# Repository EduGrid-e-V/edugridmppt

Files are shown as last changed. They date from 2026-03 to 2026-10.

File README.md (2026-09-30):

<p align="center">
  EduGrid logo
</p>

<h1 align="center">EduGrid MPPT</h1>

<p align="center">
  <strong>Learn solar energy by trying it.</strong><br>
  A friendly, open-source learning kit for renewable energy education.
</p>

<p align="center">
  Sun icon
  &nbsp;&nbsp;
  Learning icon
</p>

EduGrid MPPT is part of the EduGrid e.V initiative for free education in renewable energies. It is made for students, teachers, workshops, and curious people who want to understand solar power with their own hands.

You do not need to be an expert to begin. Start by moving the slider, watching the display, and seeing how much power a small solar panel can produce. Later, when you feel ready, you can open the code and teach the board your own strategy for finding more power.

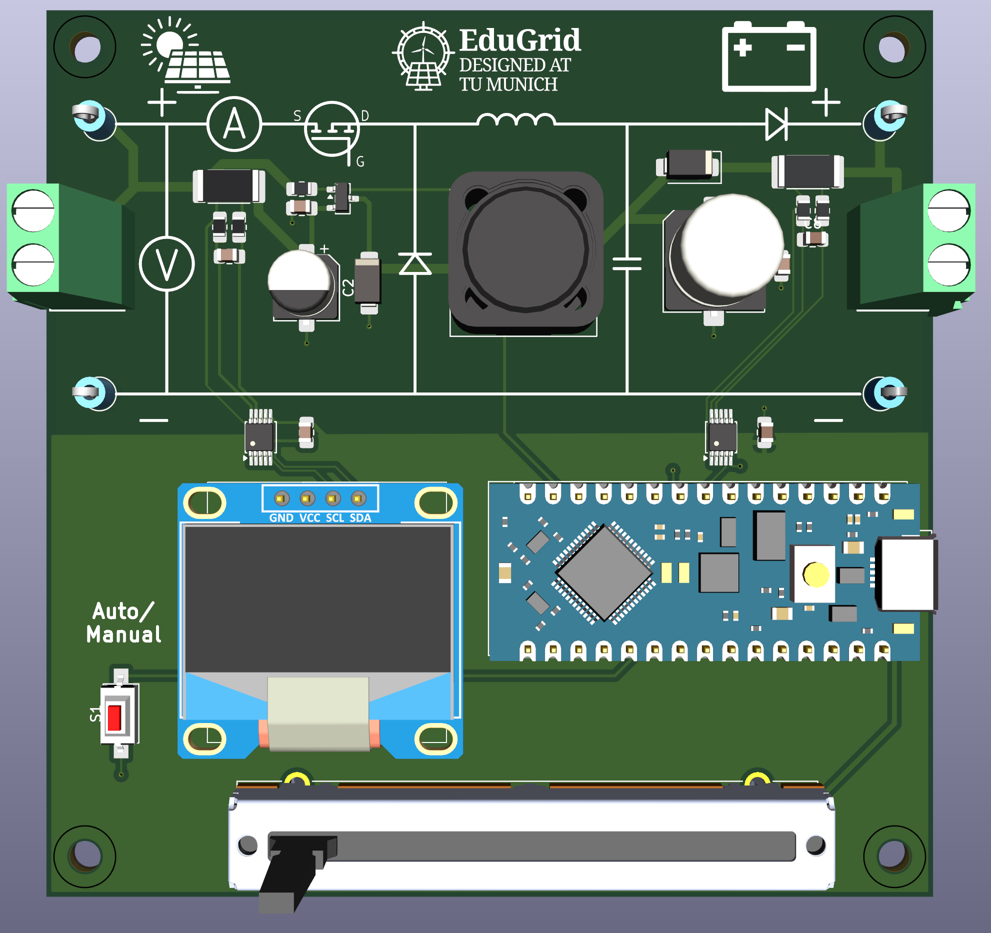
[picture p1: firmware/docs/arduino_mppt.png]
EduGrid MPPT board


## What You Can Discover

- How sunlight becomes electrical power.
- Why a solar panel has a "best point" where it gives the most energy.
- How a small controller can search for that point automatically.
- How coding, electronics, and renewable energy connect in one real project.

This is not just a board and some code. It is a small learning environment: measure something real, ask why it happens, change one thing, and try again.

## Choose Your Path

| I want to... | Start here |
| --- | --- |
| learn the project step by step | [Student Workbook](docs/STUDENT_WORKBOOK.md) |
| upload the firmware to the board | [Firmware Instructions](firmware/README.md) |
| look at the circuit and PCB | [Hardware Files](hardware/README.md) |
| explore the web dashboard | [Dashboard Source](frontend/README.md) |

## ESP32 web pages

Precompiled downloads are available from [GitHub Releases](https://github.com/EduGrid-e-V/edugridmppt/releases). Each tagged release provides an Arduino Nano `.hex`, an ESP32 `firmware.bin`, a dashboard `littlefs.bin`, and a complete ZIP with checksums, bootloader and partition images, instructions, and the standalone simulation page. GitHub Actions builds the same package on every `main` push; version tags publish it as a Release. GitLab CI also packages tagged commits as pipeline artifacts.

For an ESP32 already running the OTA-capable firmware, upload `firmware.bin` and `littlefs.bin` separately at `/admin`. The bootloader and partition images require USB flashing; do not upload them through the browser. Keep a USB recovery path available, especially for the first test release.

When connected to the board's open `EduGrid_XX` WiFi network, open
`http://192.168.4.1/` for the dashboard. In the real experiment view,
select **Downloads** in the header to find recorded CSV files. The
`/downloads` page can also be opened directly.

`http://192.168.4.1/admin` is the firmware and filesystem update page.
Neither page requires a password. Anyone connected to the open EduGrid WiFi
can update the board or delete recordings; use it in a supervised setting.
See the [firmware instructions](firmware/README.md) for the update workflow.

## For Students

Begin with the workbook and the manual experiments. Your first goal is simple: find the duty setting where the solar panel produces the most power.

When you are ready to code, your workspace is:

```text
firmware/src/mppt_alg.cpp
```

Small changes are welcome. Good experiments often begin with "What happens if I try this?"

## For Teachers

EduGrid MPPT is designed for gentle entry and deeper follow-up. A first lesson can stay fully practical: connect the board, change the operating point, and discuss power. Later lessons can introduce algorithms, sensor data, dashboards, and the structure of embedded software.

The [Student Workbook](docs/STUDENT_WORKBOOK.md) is written so it can be used in class or exported as a PDF for home study.

## The Bigger Picture

EduGrid e.V works to make renewable energy education freely available. This project supports that mission with open learning material, open hardware files, and firmware that students can actually read and change.

Renewable energy becomes less mysterious when learners can touch it, measure it, and improve it. That is the spirit of EduGrid MPPT.

## License

Hardware, firmware, and documentation are each released under different open licenses. See [LICENSE.md](LICENSE.md) for details.

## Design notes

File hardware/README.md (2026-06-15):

# EduGrid MPPT Hardware

This folder contains the KiCad hardware design files for the EduGrid MPPT trainer.

## Main Files

| File or folder | Purpose |
| --- | --- |
| `mppt.kicad_pro` | KiCad project file |
| `mppt.kicad_sch` | Schematic |
| `mppt.kicad_pcb` | PCB layout |
| `library/Library.pretty/` | Project footprints |
| `library/3dmodels/` | 3D models used by the board |
| `mppt-backups/` | KiCad backup files |

## Related Documentation

- [Student Workbook](../docs/STUDENT_WORKBOOK.md) explains the system concept and classroom experiments.
- [Firmware README](../firmware/README.md) explains the firmware, board controls, and supported build environments.

## Notes For Students

The hardware is the physical part of the MPPT system: solar panel input, buck converter power stage, INA226 sensors, OLED display, button, potentiometer, and the Arduino Nano or Arduino Nano ESP32.

When reading the schematic, try to connect each block to the firmware modules:

- Sensors in hardware are read by `firmware/src/sensor_manager.cpp`.
- The gate driver/PWM path is controlled by `firmware/src/pwm_manager.cpp`.
- Button and potentiometer are handled by `firmware/src/input_manager.cpp`.
- Display wiring is used by `firmware/src/display_manager.cpp`.

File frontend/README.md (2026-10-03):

# EduGrid MPPT Dashboard

This is the browser dashboard for the EduGrid MPPT trainer. The same Vue source has two compile-time targets:

- The firmware target is served by the ESP32 from LittleFS and talks to the firmware through WebSockets and HTTP endpoints.
- The standalone target starts in simulation mode and includes the Berry Algorithm Lab in one offline HTML file.

The built dashboard is intentionally self-contained. It should not rely on external CDNs because the ESP32 usually serves it from its own access point. The header language selector switches the dashboard, charts, Berry guidance, and logging UI between English, German, and Spanish immediately. The initial language follows the browser locale; student-edited Berry code is never translated or overwritten. The same built-in translations ship in both firmware and standalone builds, with no runtime network request.

The small header badge shows the build version from `frontend/package.json`. The current `-dev` suffix marks an unreleased build; only a separate Git release tag publishes a release.

## Project Layout

```text
frontend/
  index.html
  package.json
  vite.config.js
  src/
    App.vue
    components/
    services/
```

Key services:

- `src/simulation/SimpleSimulation.js` is the single model used by both frontend simulation paths. It represents the classroom panel as nominally 13.5 V open circuit (capped at 14 V), 180 mA short circuit, and approximately 2 W maximum power, with a fixed 25 ohm load. Manual duty and Berry output span 0–100%; simulated
  0% is the panel open-circuit state.
- `src/services/SimulationWorkerConnector.js` connects all simulation modes—including development and the ESP-hosted page—to the same worker.
- `src/workers/simulation.worker.js` owns the model, real Berry 1.1.0 interpreter, and benchmark in both builds. The firmware build uses an external worker file; the standalone build inlines it for `file://` use.
- The optional physics-model prototype is preserved on the `pv-sim` branch; neither dashboard build depends on it.
- `src/services/EspConnector.js` connects to the ESP32 using `/ws`, `/api/set`, `/api/sweep`, and `/api/sweepdata`.
- `src/components/SimulationScene.vue` only visualizes the sky and emits environmental inputs; it is not a physical model.

## Requirements

- Node.js 20 or newer is recommended for the current Vite version.
- npm
- PlatformIO, when uploading the firmware or LittleFS image to the ESP32.

Install frontend dependencies from this folder:

```bash
cd frontend
npm install
```

## Develop Locally

Start the Vite development server:

```bash
cd frontend
npm run dev
```

Open the URL printed by Vite, usually:

```text
http://localhost:5173
```

In this mode the dashboard automatically uses the simulation worker, so controls, charts, sweeps, and Berry code work without an ESP32 connected.

## Build For The ESP32

Create the ESP32 build:

```bash
cd frontend
npm run build:firmware
```

The Vite config writes the built files directly into:

```text
../firmware/data
```

That directory is the LittleFS data folder served by the ESP32 firmware. The build uses relative asset paths, so the dashboard can be served from the device without a separate web server or internet connection.

This target offers Student / Berry in both Real and Sim modes. Sim runs the same `SimpleSimulation` and Berry interpreter as the standalone page; Real sends the program to the ESP32 after a browser-side compile check. Both browser functions share one external worker, loaded only when Sim is selected or **Install & Run** is pressed. The ESP32 still compiles uploaded source and enforces runtime limits independently. The worker is about 375 kB on LittleFS and runs in the browser, not on the ESP32; the complete dashboard uses about 576 kB of LittleFS. These are uncompressed file sizes, so a browser connected to the ESP32 access point may transfer the full worker file on first use. In the real Berry view, CSV logging replaces the benchmark; the files are stored on the ESP32. The real dashboard header has a Downloads button that opens /downloads directly.

## Build The Standalone Algorithm Lab

```bash
cd frontend
npm run build:standalone
```

The generated file is `frontend/dist/edugrid-mppt.html`. It contains its scripts, styles, worker, and Berry WebAssembly runtime inline and can be opened directly with `file://`. It is not a LittleFS artifact and must not be copied into `firmware/data`.

`frontend/dist/edugrid-mppt.html` is generated output. Never edit it manually.

The simulated sweep is intentionally broader than a hardware sweep: it samples the complete model curve from 0 V/short circuit through 13.5 V/open circuit. Live operation uses the model's fixed 25 ohm load. The synthetic cloudy-day benchmark varies the whole panel's irradiance; it does not simulate cell-level partial shading or multiple power peaks.

## Upload To The Device

After building the frontend, upload the LittleFS image from the firmware project:

```bash
cd ../firmware
pio run -e esp32dev -t uploadfs
```

Then upload or re-upload the firmware if needed:

```bash
pio run -e esp32dev -t upload
```

For the Arduino Nano ESP32 environment, use:

```bash
pio run -e arduino_nano_esp32 -t uploadfs
pio run -e arduino_nano_esp32 -t upload
```

Once the ESP32 is running, connect to its Wi-Fi access point and open the device IP address printed in the serial monitor.

## Firmware API Used By The Dashboard

The production dashboard expects the firmware to provide:

- `GET /api/set?mode=AUTO|MANUAL`
- `GET /api/set?algo=PNO|INCCOND`
- `GET /api/set?duty=<number>`
- `GET /api/sweep`
- `GET /api/sweepdata`
- `WS /ws` for live telemetry

Telemetry packets are expected to include the current operating values. The frontend currently reads these short keys:

```json
{
  "v": 17.2,
  "c": 1.4,
  "p": 24.1,
  "d": 0.42,
  "m": "AUTO"
}
```

## Useful Commands

```bash
npm run dev               # local simulation dashboard
npm run build:firmware    # small real-board dashboard in firmware/data
npm run build:standalone  # one offline frontend/dist/edugrid-mppt.html
npm run check             # tests, both builds, isolation checks, file:// smoke test
```

## Notes

- Do not commit `node_modules`.
- Build output is generated from this frontend source.
- If the dashboard works locally but not from the ESP32, check the browser console, the serial monitor, and whether `pio run -t uploadfs` was run after the latest frontend build.

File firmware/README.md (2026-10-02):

# EduGrid MPPT Firmware

Firmware for the EduGrid MPPT trainer. It runs on the classic Arduino Nano and the Arduino Nano ESP32. The Nano ESP32 build also serves the WiFi dashboard from `firmware/data/`.

## Features

- Arduino Nano and Arduino Nano ESP32 support
- Student MPPT workspace in `src/mppt_alg.cpp`
- Short student API: `PV.getVoltage()`, `PV.getPower()`, `load.getVoltage()`, `duty.set()`, `duty.change()`
- Panel/input INA226 plus optional load/output INA226
- OLED telemetry with SSD1306 default and SH1106 option
- Manual duty control with button and potentiometer
- Nano ESP32 WiFi dashboard with live telemetry, manual duty, algorithm selection, and I–V sweep
- Restricted Berry 1.1.0 student algorithms on the Nano ESP32

## Hardware

- Microcontroller: Arduino Nano ATmega328P or Arduino Nano ESP32
- Gate PWM: `D9` on classic Nano, `D5` on Nano ESP32
- Button: `D3`
- Potentiometer: `A7`
- Panel/input INA226: I2C address `0x40`
- Optional load/output INA226: I2C address `0x41`
- OLED: I2C address `0x3C`, fallback `0x3D`

Current OLED default:

```cpp
#define OLED_CONTROLLER OLED_CONTROLLER_SSD1306
```

Switch to SH1106 in `include/config.h` if your display needs it.

## Important Nano ESP32 Potentiometer Note

The Nano ESP32 analog pins are 3.3 V inputs. Do not feed a 5 V potentiometer wiper directly into an ADC pin.

For the next hardware revision:

- Power the potentiometer from `3V3` or `IOREF`, not fixed `5V`.
- If WiFi must stay on, choose an ADC pin that behaves reliably while WiFi is active.
- Keep the firmware pin in one place: `POT_PIN` in `include/config.h`.

## Build Environments

From this `firmware/` folder:

```bash
pio run -e nanoatmega328new
pio run -e arduino_nano_esp32
```

PlatformIO environments:

| Environment | Board |
| --- | --- |
| `nanoatmega328new` | Classic Arduino Nano |
| `arduino_nano_esp32` | Arduino Nano ESP32 |

The old generic `esp32dev` environment has been removed.

## Upload

Use the PlatformIO sidebar or:

```bash
pio run -e nanoatmega328new -t upload
pio run -e arduino_nano_esp32 -t upload
```

For the Nano ESP32 dashboard, also upload the filesystem image:

```bash
pio run -e arduino_nano_esp32 -t uploadfs
```

### Browser updates after the first USB installation

The Nano ESP32 firmware contains a recovery page that does not depend on the
dashboard filesystem. After one USB installation of this firmware, subsequent
application and dashboard updates can be installed over the board's WiFi:

1. Connect to the board's open `EduGrid_XX` access point.
2. Open `http://192.168.4.1/admin`; no login or password is required.
3. Upload either the application image or the LittleFS image.
4. Confirm the upload and keep the board powered until it restarts.

**Classroom access warning:** anyone connected to this open access point can replace
the firmware or filesystem. Only power it up in a supervised setting and keep
the upload files and a USB recovery path available.

Build the upload files with:

```bash
pio run -e arduino_nano_esp32
pio run -e arduino_nano_esp32 -t buildfs
```

The files are written to:

```text
.pio/build/arduino_nano_esp32/firmware.bin
.pio/build/arduino_nano_esp32/littlefs.bin
```

Firmware OTA writes to the inactive 3 MiB application slot. The Arduino framework
used by this project does not enable automatic boot rollback, so keep the initial
USB installation available until an OTA firmware has been tested on hardware. A
filesystem upload replaces the single LittleFS partition and therefore is not
power-failure atomic.
The recovery page remains available if LittleFS is damaged, so a valid filesystem
image can be uploaded again. `/student.be`, when present, is backed up to NVS and
restored after a successful filesystem update.

Before either upload starts, the firmware stops an active sweep and holds the
converter at minimum duty. The normal control loop remains disabled until the
upload fails or the board restarts.

The browser updater intentionally does not replace the bootloader or partition
table. Changes to either still require a USB connection.

The board creates an open WiFi access point whose final two hexadecimal
characters come from the last octet of its factory MAC address. This usually
distinguishes nearby boards, but a one-byte suffix is not guaranteed unique.
Its OLED shows the network and page
addresses for the first 15 seconds after power-up, for example:

```text
EduGrid WiFi (open)
SSID: EduGrid_A3
192.168.4.1
Updates: /admin
Files: /downloads
```

## Controls

| Input | Action |
| --- | --- |
| Short button press | Toggle Auto / Manual mode |
| Long button press | Cycle Incremental Conductance and P&O; on Nano ESP32, also Student / Berry |
| Slide potentiometer | Set duty cycle in Manual mode |
| Web dashboard | Set mode, duty, algorithm, and start an I–V sweep |

## Berry on the Nano ESP32

The ESP32 dashboard can compile, install, and run the same `mppt()` Berry program
used by the standalone simulator. Select **Student / Berry**, edit the program,
then select **Install & Run**. The source is compiled on the ESP32 and the last
verified program is stored as `/student.be` in LittleFS.

The embedded runtime exposes only `PV`, `load`, and `duty`. Filesystem, OS,
network, debug, introspection, shared-library, and bytecode-file modules are
disabled. Firmware—not student code—applies the resulting duty cycle. Each call
has a 20 ms wall-clock limit, duty remains inside the configured PWM limits, and
one call can change duty by at most 0.05. A timeout, runtime error, or non-finite
duty disables execution and moves PWM to minimum duty.

Berry management API:

| Endpoint | Purpose |
| --- | --- |
| `POST /api/berry` | Compile and atomically install a plain-text Berry program |
| `GET /api/berry` | Read installation health, diagnostics, and active source |
| `DELETE /api/berry` | Remove the active and saved student program |

A failed upload never replaces the previous valid VM or saved source. This is a
software safety boundary, not a substitute for the converter's electrical
current limiting and physical protections.

## Real-experiment CSV logging

On the ESP32 dashboard, select Real and Student / Berry. The panel provides
Start logging and Stop logging at 1 s, 30 s, 1 min, or 5 min intervals. Only
real sensor readings are recorded; the standalone simulation retains Benchmark.

Recordings are saved as /logs/run-0001.csv etc. in LittleFS. Select the
Downloads button in the real dashboard header, or open /downloads on the
device access point, to download or delete older files without a password. The CSV columns are elapsed
seconds, PV voltage (V), PV current (A), load voltage (V), load current (A),
and duty cycle (0-1). Missing load-sensor readings are blank.

CSV data is capped at 4 MiB and 64 files, with at least 256 KiB free space
reserved. At a conservative 64 bytes per row, 4 MiB holds approximately
18 hours at 1 s, 23 days at 30 s, 46 days at 1 min, or 228 days at
5 min; headers, filesystem overhead, and existing files reduce that.
Storage full or write failure stops recording. OTA closes the active CSV.
A firmware-only update normally leaves LittleFS intact; a filesystem update
replaces it and may erase all recordings. Download files you want to keep first.

Logger API: GET /api/logging returns status and file list;
POST /api/logging/start?intervalS=1|30|60|300 starts a run;
POST /api/logging/stop closes it; GET /api/logging/file?name=run-0001.csv
downloads it. DELETE on the same file URL deletes it without authentication.

## Student Workspace

On the Nano ESP32, students write and install their algorithm in the dashboard's
**Student / Berry** editor. The **P&O** selection always runs the built-in
reference controller. The C++ workspace below remains for optional source-code
exercises, but the standard firmware does not select it:

```text
src/mppt_alg.cpp
```

The short API is meant for student code:

```cpp
PV.getVoltage();
PV.getCurrent();
PV.getPower();

load.getVoltage();
load.getCurrent();
load.getPower();
load.isAvailable();

duty.get();
duty.set(0.50f);
duty.change(+smallDutyCycleStep);
```

Longer names such as `measurement.panelVoltageVolts` still work and are useful when teaching structs, but the short API is the preferred beginner path.

Important buck converter rule for this kit:

```text
Increasing duty cycle usually lowers the panel voltage.
Decreasing duty cycle usually raises the panel voltage.
```

## Measurement Filtering

The INA226 is configured for internal averaging. The extra software IIR filter is located in `src/sensor_manager.cpp`, but is disabled by default:

```cpp
#define ENABLE_SENSOR_IIR_FILTER 0
```

Enable it in `include/config.h` only if you want additional smoothing after the INA226 readings.

## Configuration

Most project settings live in:

```text
include/config.h
```

Useful settings:

| Setting | Meaning |
| --- | --- |
| `PWM_MIN_DUTY`, `PWM_MAX_DUTY` | Allowed duty cycle range |
| `DUTY_STEP_START` | Default MPPT step size |
| `VIN_VALID_MIN` | Minimum panel voltage before MPPT runs |
| `INA_AVERAGE_MODE` | INA226 internal averaging |
| `ENABLE_SENSOR_IIR_FILTER` | Optional software sensor smoothing |
| `OLED_CONTROLLER` | SSD1306 or SH1106 display driver |
| `ENABLE_WIFI_DASHBOARD` | Nano ESP32 dashboard on/off |

The active firmware and dashboard accept 0–100% duty. On the AVR board, 0%
disconnects the timer output and drives the gate low; 100% holds the PWM output
high. The ESP32 uses the pinned Arduino LEDC implementation. This range is
not a substitute for checking gate polarity and component temperatures on the
physical kit before prolonged endpoint operation.

## Serial Monitor

Use `115200` baud. Startup messages show sensor and OLED status.

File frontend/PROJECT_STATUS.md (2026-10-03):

# EduGrid MPPT - Project Status

## Project Overview
This repository is now a combined EduGrid MPPT project with:

*   **`frontend/`**: Vue 3 + Vite dashboard served offline from ESP32 LittleFS.
*   **`firmware/`**: PlatformIO Arduino firmware for the MPPT board.
*   **`hardware/`**: PCB/library hardware files.

The dashboard communicates with the board through:

*   **WebSocket `/ws`** for live telemetry.
*   **HTTP `/api/*`** for commands such as mode changes, duty-cycle changes, algorithm selection, sweep start, and sweep data fetch.

## Frontend Status

### Dashboard Design
*   Reworked into a clean, mobile-friendly lab dashboard for high-school and early engineering students.
*   Uses the EduGrid identity in the header with a light, structured interface.
*   Graphs were rebuilt as responsive SVG charts instead of fixed canvas/uPlot layouts.
*   Graph cards now have clear light tiles, inset plot areas, readable axis labels, and mobile-friendly sizing.

### Controls
*   `ControlPanel.vue` shows:
    *   Panel/input power, voltage, current.
    *   Load/output power, voltage, current when the second INA226 is detected.
    *   Manual duty-cycle slider.
    *   Auto/manual mode selection.
    *   MPPT algorithm selection.
    *   Sweep trigger.
*   Fixed the manual duty slider reset issue:
    *   Missing telemetry fields no longer reset duty to `0`.
    *   Missing telemetry mode no longer forces `MANUAL`.
    *   Firmware now sends duty/mode/algorithm with live telemetry.

### Telemetry Parsing
*   `EspConnector.js` normalizes panel-side values:
    *   `v`, `i`/`c`, `p`
*   It also normalizes load-side values:
    *   `loadV`, `loadI`, `loadP`, `loadSensor`
*   Sweep data can now include load-side arrays as well.

### Simulation Mode
*   `SimulationWorkerConnector.js` connects the ESP-hosted and standalone dashboards to one browser worker.
*   The worker uses `SimpleSimulation` for panel and load readings and runs built-in or student Berry MPPT algorithms without hardware.

## Firmware Status

### Educational Refactor
The firmware was refactored so students mainly work in:

```text
firmware/src/mppt_alg.cpp
```

The rest of the firmware abstracts hardware details:

*   `sensor_manager.*`: INA226 readings.
*   `pwm_manager.*`: PWM/duty-cycle output.
*   `display_manager.*`: OLED display.
*   `wifi_manager.*`: dashboard API and WebSocket.
*   `sweep_manager.*`: sweep scan and sweep data.
*   `input_manager.*`: button and potentiometer.

### Student MPPT Interface
`mppt_alg.cpp` now contains a clearly marked section:

```cpp
/*
 * ##### YOUR CODE GOES HERE #####
 */
```

Students receive a readable measurement object:

```cpp
measurement.panelVoltageVolts
measurement.panelCurrentAmps
measurement.panelPowerWatts
measurement.loadVoltageVolts
measurement.loadCurrentAmps
measurement.loadPowerWatts
measurement.loadSensorIsAvailable
measurement.converterDutyCycle
```

Students can control the converter with:

```cpp
getConverterDutyCycle()
setConverterDutyCycle(0.50f)
changeConverterDutyCycle(+smallDutyCycleStep)
changeConverterDutyCycle(-smallDutyCycleStep)
```

`P&O` currently maps to the student/example algorithm area. `IncCond` remains available as a reference implementation.

### Main Loop Cleanup
`main.cpp` now uses verbose variable names such as:

*   `filteredPanelVoltageVolts`
*   `filteredPanelCurrentAmps`
*   `filteredPanelPowerWatts`
*   `filteredLoadVoltageVolts`
*   `filteredLoadCurrentAmps`
*   `filteredLoadPowerWatts`
*   `currentTimeMilliseconds`

The loop is split into readable helper functions for input handling, soft start, sensor filtering, dashboard telemetry, and auto/manual control.

### Second INA226 Support
The new board revision with a second INA226 is supported.

Default addresses in `firmware/include/config.h`:

```cpp
#define PANEL_INA_ADDR  0x40
#define LOAD_INA_ADDR   0x41
```

The panel/input INA226 is required for MPPT. The load/output INA226 is optional:

*   If detected, its voltage/current/power are displayed and sent to the dashboard.
*   If not detected, the firmware still runs and reports `loadSensor = false`.

### Dashboard Telemetry
Live WebSocket telemetry now includes:

```json
{
  "v": 0,
  "i": 0,
  "p": 0,
  "loadV": 0,
  "loadI": 0,
  "loadP": 0,
  "loadSensor": true,
  "d": 0,
  "m": "AUTO",
  "algo": "PNO"
}
```

This fixed frontend state synchronization for:

*   Manual duty slider.
*   Auto/manual mode display.
*   Algorithm display.

## Build And Upload Workflow

From repository root:

```bash
cd frontend
npm run build
```

Vite writes directly into:

```text
firmware/data/
```

This is configured in:

```text
frontend/vite.config.js
```

with:

```js
build: {
  outDir: '../firmware/data',
  emptyOutDir: true,
}
```

Then upload the filesystem and firmware from:

```bash
cd ../firmware
pio run -e arduino_nano_esp32 -t uploadfs
pio run -e arduino_nano_esp32 -t upload
```

PlatformIO expects the project folder to be `firmware/`, because `platformio.ini` lives there.

## Verified Builds

The following commands pass:

```bash
pio run -e arduino_nano_esp32
pio run -e nanoatmega328new
npm run build
```

## Known Issue

Uploading to the Arduino Nano ESP32 on Ubuntu still fails intermittently/currently with:

```text
Failed to connect to ESP32-S3: No serial data received.
```

Notes:

*   The board is detected as `/dev/ttyACM0`.
*   Updating esptool from 4.7 to 5.2 was tested and did not fix the upload issue.
*   The esptool change was reverted; PlatformIO is back to its normal `tool-esptoolpy @ 1.40700.0 (4.7.0)`.
*   PlatformIO warns that `/etc/udev/rules.d/99-platformio-udev.rules` are outdated.
*   Likely next steps are fixing udev rules and/or manually entering bootloader mode before upload.

## Current Next Steps

1.  Resolve Arduino Nano ESP32 upload/bootloader issue on Ubuntu.
2.  Test second INA226 on the new board revision and confirm `LOAD_INA_ADDR`.
3.  Add live sweep progress over WebSocket so the dashboard can show the sweep dot moving during the scan.
4.  Consider a student worksheet/example around the `##### YOUR CODE GOES HERE #####` section.

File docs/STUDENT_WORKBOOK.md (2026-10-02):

# EduGrid MPPT Student Workbook

This workbook introduces the EduGrid MPPT project to students who are new to coding and Maximum Power Point Tracking. It is designed for supervised classroom work, but the reference appendices also support independent preparation.

The learning path is deliberately practical:

> **Find a maximum by hand → lose it → invent a rule → test the rule → only then meet the named algorithm.**

The main student coding file is:

```text
firmware/src/mppt_alg.cpp
```

The rest of the firmware reads sensors, drives the converter, updates the display, and serves the optional Nano ESP32 dashboard.

## Contents

1. [Before You Start](#1-before-you-start)
2. [What A Solar Panel Does](#2-what-a-solar-panel-does)
3. [Experiment 1: Find The Maximum By Hand](#3-experiment-1-find-the-maximum-by-hand)
4. [Experiment 2: Lose It And Get It Back](#4-experiment-2-lose-it-and-get-it-back)
5. [Experiment 3: Write Down Your Rule](#5-experiment-3-write-down-your-rule)
6. [Experiment 4: Trade Rules With Another Group](#6-experiment-4-trade-rules-with-another-group)
7. [What You Invented Is Called Perturb And Observe](#7-what-you-invented-is-called-perturb-and-observe)
8. [Experiment 5: Put Your Rule Into The Code](#8-experiment-5-put-your-rule-into-the-code)
9. [Experiment 6: Change The Step Size](#9-experiment-6-change-the-step-size)
10. [A Second Idea: Incremental Conductance](#10-a-second-idea-incremental-conductance)
11. [Experiment 7: Compare The Two Algorithms](#11-experiment-7-compare-the-two-algorithms)
12. [Experiment 8: Use The Dashboard And The Sweep](#12-experiment-8-use-the-dashboard-and-the-sweep)
13. [How The Board Works](#13-how-the-board-works)
14. [Experiment 9: Trace One Measurement Through The Code](#14-experiment-9-trace-one-measurement-through-the-code)
15. [Reference Appendices](#appendix-a-c-you-will-meet-in-this-project)

---

## 1. Before You Start

### How to use this workbook

1. Begin with Experiment 1 rather than reading every appendix.
2. Make a prediction before moving a control.
3. Record what the display actually shows, including values that are not round.
4. Change one thing at a time whenever possible.
5. Keep failures visible. A rule that oscillates or gets stuck is useful evidence.
6. Follow links to the appendices only when an experiment needs them.

Teacher pacing idea:

| Lesson | Main goal | Activity |
| --- | --- | --- |
| 1 | Voltage, current, power, and what a panel does | Experiments 1 and 2 |
| 2 | Invent a tracking rule | Experiments 3 and 4, then Section 7 |
| 3 | Basic C++ for this project | Appendix A, then Experiment 5 |
| 4 | Make the rule work well | Experiment 6 |
| 5 | Compare two algorithms | Section 10 and Experiment 7 |
| 6 | See the whole system | Experiments 8 and 9 |

### What you need

- An EduGrid MPPT board with the correct firmware for its microcontroller.
- A small PV module and a teacher-approved light source.
- A suitable resistive load connected to the converter output.
- USB power/programming cable and a computer with PlatformIO.
- A notebook or this printed workbook.
- For Experiment 8: an Arduino Nano ESP32 and a phone or laptop with WiFi.

### Safety notes

- Do not exceed the voltage, current, temperature, or component limits given by the teacher.
- Shorting the **panel** is safe: a solar panel limits its own current, and the short-circuit current `I_sc` is one of the numbers on its datasheet. Shorting the **converter output** is not safe: the output capacitor can deliver a large current for a short time. Do not short the output.
- De-energize the setup before changing wiring.
- A lamp, load resistor, diode, inductor, and MOSFET can become hot. Stop if a component heats unexpectedly.
- If measurements look strange, stop changing code and check wiring first.
- MPPT code can move the converter operating point quickly. Begin with small duty-cycle steps.

---

## 2. What A Solar Panel Does

A solar panel is not an ideal battery. Its voltage and current depend on illumination, temperature, and the electrical load.

Three quantities matter throughout the workbook:

| Quantity | Symbol | Unit | Meaning |
| --- | --- | --- | --- |
| Voltage | `V` | volts (V) | Electrical potential difference |
| Current | `I` | amperes (A) | Flow of charge |
| Power | `P` | watts (W) | Energy transferred per second |

The key equation is:

```text
Power = Voltage × Current
P = V × I
```

For example:

```text
5.0 V × 0.12 A = 0.60 W
```

Solar-panel I–V and P–V curves

The current–voltage plot is called an **I–V curve**. The power–voltage plot is called a **P–V curve**. Both share voltage on the horizontal axis.

- At short circuit, voltage is near zero. Current can be high, but `P = V × I` is zero.
- At open circuit, current is zero. Voltage can be high, but power is again zero.
- Between those endpoints, the product `V × I` has a maximum.

That peak is the **maximum power point**, or MPP. Its voltage, current, and power are often written as `V_mpp`, `I_mpp`, and `P_mpp`. The best point moves when light, shade, or temperature changes.

---

## 3. Experiment 1: Find The Maximum By Hand

**Goal:** discover the panel's power peak before writing an algorithm.

### Predict

The slider changes how strongly the converter loads the panel. Before touching it, predict:

- Which end will leave the panel close to open circuit?
- As duty cycle increases, will panel voltage rise or fall?
- Will maximum power occur at an end or somewhere in between?

Write your prediction:

```text

```

If you want the mechanism before testing your prediction, see [Section 13.4](#134-how-the-slider-moves-the-operating-point). Otherwise, test first and return to the explanation later.

### Steps

1. Upload the firmware and connect the teacher-approved panel and load.
2. Use a short button press to select **Manual** mode.
3. Move the slider a little at a time, from one end to the other.
4. At each stop, write down the duty cycle shown on the display — whatever it happens to be — together with voltage, current, and power.
5. Aim for about nine readings spread across the whole travel.
6. Plot power against duty cycle and mark the highest measured point.

| Reading | Duty shown | Panel voltage (V) | Panel current (A) | Panel power (W) | Observation |
| ---: | ---: | ---: | ---: | ---: | --- |
| 1 | | | | | |
| 2 | | | | | |
| 3 | | | | | |
| 4 | | | | | |
| 5 | | | | | |
| 6 | | | | | |
| 7 | | | | | |
| 8 | | | | | |
| 9 | | | | | |

### Questions

1. At which measured duty cycle was power highest?
2. What happened to panel voltage as duty cycle increased?
3. Was the curve smooth or noisy?
4. Did the best duty cycle stay at one of the ends?
5. Write one sentence describing how you would find the best duty cycle again if the light changed.

```text
My first tracking rule:

```

---

## 4. Experiment 2: Lose It And Get It Back

**Goal:** recover maximum power after the environment moves it, without sweeping the entire slider again.

### Steps

1. Return to the best duty setting you found in Experiment 1.
2. Record the starting voltage, current, power, and duty.
3. Change the light in one teacher-approved way: move the lamp farther away, or let a hand or card cast a partial shadow.
4. Do **not** sweep the slider from end to end.
5. Use only the numbers on the display to decide which way to move.
6. Count each slider move until you believe you have found the new maximum.
7. Confirm with a few small moves on either side.

| Stage | Duty shown | Voltage (V) | Current (A) | Power (W) | Move made |
| --- | ---: | ---: | ---: | ---: | --- |
| Before light change | | | | | — |
| Immediately after change | | | | | — |
| Move 1 | | | | | |
| Move 2 | | | | | |
| Move 3 | | | | | |
| Move 4 | | | | | |
| Best recovered point | | | | | |

Number of moves needed: __________

### Questions

1. What told you that the original setting was no longer best?
2. How did you decide the direction of your first move?
3. How did you decide when to reverse direction?
4. How did you decide when to stop?
5. Rewrite your one-sentence tracking rule from Experiment 1 if the evidence changed it.

---

## 5. Experiment 3: Write Down Your Rule

**Goal:** turn your successful hand movements into instructions another group can execute without discussion.

A rule needs enough detail to remove hidden decisions. Here is an example of the **format**, using an unrelated number-guessing task:

> Start at 50. Ask whether the hidden number is higher or lower. Move halfway toward the indicated end of the remaining range. Repeat until the answer is correct.

This example shows a start, a measurement, a comparison, a direction, a step size, and a stopping condition. It does **not** give the content of a solar tracking rule.

### Write your group's rule

| Decision | Your instruction |
| --- | --- |
| What do you measure first? | |
| What previous value do you compare it with? | |
| How do you decide which way to move? | |
| How far do you move each time? | |
| What do you do when the value becomes worse? | |
| When do you stop or hold? | |
| What happens if two readings are almost equal? | |

Now write the complete rule. Another group must be able to follow it without asking what you meant.

```text

```

---

## 6. Experiment 4: Trade Rules With Another Group

**Goal:** expose ambiguity by executing another group's written rule exactly as written.

### Steps

1. Exchange written rules with another group. Do not explain your rule aloud.
2. Put the board in Manual mode and start away from the best point.
3. Execute the other group's instructions literally.
4. If a step is unclear, do not silently repair it. Record the ambiguity.
5. If the rule gets stuck or oscillates, keep that failure visible and record it.
6. Introduce one light change and see whether the rule can recover.
7. Return the rule with evidence and revise your own rule.

| Test | What happened? | Evidence from display | Exact place the rule was unclear |
| --- | --- | --- | --- |
| Starting away from MPP | | | |
| Near the peak | | | |
| After a light change | | | |

| Failure mode | Seen? | What caused it? |
| --- | :---: | --- |
| Direction was ambiguous | | |
| Step size was unspecified | | |
| Rule got stuck | | |
| Rule oscillated around the peak | | |
| Passing shade looked like an effect of the last move | | |

### Questions

1. Which instruction was obvious to its author but not to its reader?
2. Did the rule distinguish a control change from an environmental change?
3. What would make the rule faster? What would make it steadier?
4. Write one revision that another group can test.

---

## 7. What You Invented Is Called Perturb And Observe

**Perturb** means change something a little. **Observe** means measure what happened.

Perturb and Observe flowchart

A tidy Perturb and Observe (P&O) rule is:

```text
Perturb the duty cycle by one step.
Measure voltage and current, then calculate power.
Compare the new power with the previous power.
If power improved, continue in the same direction.
If power became worse, reverse direction.
Repeat.
```

You already met its strengths and weaknesses by hand.

**Strengths**

- It is simple and uses measurements the board already has.
- It does not need a stored model of the panel.
- It can follow a peak that moves.

**Weaknesses**

- It normally oscillates around the maximum rather than stopping exactly on it.
- Large steps react quickly but waste more power near the peak.
- Small steps are steadier but recover slowly.
- If irradiance changes between measurements, P&O can mistake that change for the effect of its own perturbation.

The last weakness explains why the passing-cloud failure in Experiment 4 matters: an algorithm sees numbers, not causes.

---

## 8. Experiment 5: Put Your Rule Into The Code

**Goal:** translate the rule your group wrote in Experiment 3 into C++.

**Current firmware:** this is an optional C++ source-code exercise. The standard P&O
selection runs the built-in controller; use Student / Berry on the ESP32 dashboard
to install and test your own algorithm on the kit.

Open:

```text
firmware/src/mppt_alg.cpp
```

The student function is:

```cpp
void runStudentMpptAlgorithm(const SolarPanelMeasurement& measurement)
```

Useful short API:

```cpp
PV.getVoltage();
PV.getCurrent();
PV.getPower();

load.getVoltage();
load.getCurrent();
load.getPower();
load.isAvailable();

duty.get();
duty.set(0.50f);
duty.change(+smallDutyCycleStep);
duty.change(-smallDutyCycleStep);
```

### Rules

- Edit only between the student-section markers in `runStudentMpptAlgorithm()`.
- Keep `rememberMeasurement(measurement);` after the student section.
- Use `duty.change(...)` or `duty.set(...)`; do not write PWM registers directly.
- Start with small changes.
- Translate **your group's written rule**, not a supplied algorithm.
- Add comments that connect each code decision to one instruction in your rule.

### Important selection check

The board starts in **Incremental Conductance** because `DEFAULT_MPPT_ALGORITHM` is `ALGO_INCCOND`.
Selecting **P&O** runs the built-in reference controller, not the C++ TODO above.
To run your own code on a Nano ESP32, select **Student / Berry** in the dashboard
and install a Berry program. Editing the C++ TODO alone does not change the standard firmware.

| Test | Expected behavior | Observed behavior | Change needed |
| --- | --- | --- | --- |
| First measurement | | | |
| Power improves | | | |
| Power becomes worse | | | |
| Near the peak | | | |
| Light changes | | | |

<details>
<summary><strong>Only open this if your group is stuck</strong></summary>

Fallback structure — translate it into your own variable names and explain every line:

```text
if power got smaller:
    reverse direction

move duty cycle in the current direction
```

</details>

### Extension: add a noise deadband

Only after your original rule works, try ignoring tiny changes that could be measurement noise:

```cpp
if (fabsf(changeInPanelPowerWatts) > 0.002f) {
    // Respond only when the change is large enough.
}
```

Choose the threshold from evidence rather than assuming `0.002 W` fits every setup. If C++ syntax is unfamiliar, use [Appendix A](#appendix-a-c-you-will-meet-in-this-project).

---

## 9. Experiment 6: Change The Step Size

**Goal:** measure how step size changes speed and oscillation.

In `firmware/include/config.h`, find:

```cpp
#define DUTY_STEP_START 0.01f
```

With teacher approval, test the same light change with each value:

| Step size | Behavior near maximum | Moves after light change | Best average power | Notes |
| --- | --- | ---: | ---: | --- |
| `0.002f` | | | | |
| `0.005f` | | | | |
| `0.010f` | | | | |
| `0.020f` | | | | |

> **Resolution note:** the board sets duty cycle in 255 hardware steps, so the smallest output change it can make is about `1/255 ≈ 0.004`. If you request `0.002`, the stored floating-point value still changes every time, but the converter output moves about every second step. Watch the duty cycle on the display while you try this. Can you see it?

### Questions

1. Which step size was steadiest near the maximum?
2. Which recovered fastest after the light changed?
3. Which produced the best average power over time?
4. Why might one fixed step size be a compromise?
5. Sketch an adaptive rule that changes step size without implementing it yet.

---

## 10. A Second Idea: Incremental Conductance

P&O asks whether power increased after the last move. Incremental Conductance uses the local slope of the panel curve.

```text
P = V × I
```

At the top of the power curve, its slope is nearly zero:

```text
dP/dV = 0
```

Using calculus, this becomes:

```text
dI/dV = -I/V
```

The firmware compares incremental conductance, `ΔI/ΔV`, with instantaneous conductance, `I/V`.

You do not need to master the calculus to test the decision:

- on one side of the maximum, move in one direction;
- on the other side, move in the opposite direction;
- sufficiently close to the maximum, hold duty cycle.

The reference implementation is in `firmware/src/mppt_alg.cpp` outside the student section. It uses voltage-, current-, and MPP-distance thresholds to cope with finite resolution and noise.

---

## 11. Experiment 7: Compare The Two Algorithms

**Goal:** compare the built-in P&O and Incremental Conductance algorithms under the same conditions.

### Steps

1. Use the display to confirm the built-in **P&O** algorithm is active.
2. Make one repeatable light change and count how many control updates it takes to recover.
3. Record oscillation or instability near the best point.
4. Long-press until **Incremental Conductance** appears (on ESP32, the next selection after P&O is Berry).
5. Confirm the active algorithm on the display.
6. Restore the starting conditions and repeat the same light change.
7. Repeat each test more than once; a single noisy trial is weak evidence.

| Algorithm | Fast to react? | Stable near maximum? | Confused by changing light? | Evidence |
| --- | --- | --- | --- | --- |
| Built-in P&O | | | | |
| Incremental Conductance | | | | |

### Questions

1. Which algorithm recovered in fewer updates?
2. Which oscillated less near the maximum?
3. Were differences larger than ordinary measurement variation?
4. What would you change before claiming one algorithm is better?

---

## 12. Experiment 8: Use The Dashboard And The Sweep

**Goal:** compare live measurements, your manual results, and a full I–V/P–V sweep.

### Nano ESP32 steps

1. Build and upload the correct ESP32 environment from [Appendix C](#appendix-c-build-and-upload).
2. Upload the LittleFS filesystem image.
3. After power-up, watch the OLED for the board's network name. It starts with `EduGrid_` and ends with two hexadecimal characters from the final octet of its factory MAC address, for example `EduGrid_A3`. The name remains on the OLED for the first 15 seconds.
4. Connect a phone or laptop to that exact WiFi network. In a classroom, check the suffix so you do not connect to another group's board.
5. Open `http://192.168.4.1` if the captive portal does not open automatically.
6. Observe live voltage, current, power, duty, mode, and active algorithm.
7. Start an I–V sweep.
8. Repeat with one controlled light or shade change.

| Condition | `V_oc` (V) | `I_sc` (A) | `V_mpp` (V) | `I_mpp` (A) | `P_mpp` (W) |
| --- | ---: | ---: | ---: | ---: | ---: |
| Initial light | | | | | |
| Changed light/shade | | | | | |

### Questions

1. Does the swept P–V curve agree with your manual measurements?
2. Where is the maximum power point on both plots?
3. What changed most under partial shade: voltage, current, curve shape, or all three?
4. Why should a sweep temporarily take control away from the tracker?

> The dashboard also contains a simulation mode, but this workbook does not yet use it as an experiment. Its converter and algorithm models are being aligned with the real board. Until that work is complete, simulated numbers must not be treated as measurements or as faithful algorithm evidence.

---

## 13. How The Board Works

### 13.1 Two paths meet at the converter

EduGrid MPPT system overview

- **Energy path:** panel → buck converter → load.
- **Information path:** voltage/current sensors → microcontroller → MPPT rule → PWM command.

The algorithm does not create power or change the cell's conversion efficiency. It changes the operating point and tries to capture more of the electrical power already available from the illuminated panel.

### 13.2 The actual power stage

The EduGrid board uses a **non-synchronous buck converter**:

- NTR4171PT1G P-channel MOSFET as the controlled high-side switch;
- BC817 transistor as the gate driver;
- SS26 Schottky diode as the freewheeling diode;
- 2.2 mH inductor;
- input and output capacitors;
- approximately 62.5 kHz PWM.

When the MOSFET switches off, current continues through the Schottky diode. Its forward-voltage drop is a real contributor to conversion loss and can be visible when you compare input and output power.

Two INA226 sensors use matched `0.1 Ω` shunts:

- panel/input sensor at I2C address `0x40`;
- optional load/output sensor at `0x41`.

### 13.3 PWM and duty cycle

PWM means Pulse Width Modulation. The gate signal switches rapidly between ON and OFF. Duty cycle is the fraction of each period spent ON:

```text
Duty cycle = ON time / total period
```

PWM duty-cycle examples

| Duty cycle | Meaning |
| --- | --- |
| `0.10` | ON for 10% of each cycle |
| `0.50` | ON for 50% of each cycle |
| `0.90` | ON for 90% of each cycle |

PWM is the actuation technique. MPPT is the control objective. They are not competing names for the same thing.

### 13.4 How the slider moves the operating point

The panel does not see the load resistor directly. It sees the load *through* the converter, which changes the resistance it appears to have.

For the idealized buck-converter relationship used here, with load resistance `R_load` and duty cycle `D`:

```text
R_seen = R_load / (D × D)
```

A small duty cycle makes the load look very large — almost like no load at all — so panel voltage climbs toward `V_oc`. A large duty cycle makes the apparent resistance smaller and pulls panel voltage down. Moving the slider is therefore a way of walking along the panel's I–V curve.

Because `D` cannot exceed 1, `R_seen` cannot be smaller than `R_load`. The slider can approach open circuit as `D` approaches zero, but it cannot short the panel. This is why the load resistor must be chosen below the panel's source resistance at MPP, `V_mpp / I_mpp`, if the board is to reach the peak.

The practical sign rule is:

```cpp
// Increasing duty cycle usually lowers the panel voltage.
// Decreasing duty cycle usually raises the panel voltage.
```

### 13.5 Measurement and control timing

The microcontroller repeatedly:

1. reads panel voltage and current;
2. calculates panel power;
3. runs the selected control rule;
4. changes PWM duty;
5. waits long enough for a valid next measurement.

The INA226 sensors average 16 samples internally because `INA_AVERAGE_MODE` is `2`. That is the only measurement smoothing enabled by default. Measurements can therefore still look noisy, and a useful tracking rule must cope with that.

An optional software IIR filter exists but is off by default:

```cpp
#define ENABLE_SENSOR_IIR_FILTER 0
```

### 13.6 Repository map

```text
firmware/   Code for Arduino Nano and Nano ESP32
frontend/   Source of the Nano ESP32 web dashboard
hardware/   KiCad schematic and PCB files
docs/       Learning material and diagrams
```

| File | Job |
| --- | --- |
| `firmware/src/main.cpp` | Connects modules and schedules the main loop |
| `firmware/src/mppt_alg.cpp` | Student MPPT workspace and reference IncCond |
| `firmware/src/mppt_alg_reference.cpp` | Built-in P&O controller |
| `firmware/include/mppt_alg.h` | Student-facing types and helpers |
| `firmware/src/sensor_manager.cpp` | Reads INA226 voltage/current sensors |
| `firmware/src/pwm_manager.cpp` | Generates PWM and stores duty cycle |
| `firmware/src/input_manager.cpp` | Reads the button and slide potentiometer |
| `firmware/src/display_manager.cpp` | Updates the OLED |
| `firmware/src/wifi_manager.cpp` | Serves dashboard data on ESP32 builds |
| `firmware/src/sweep_manager.cpp` | Performs an I–V sweep |
| `firmware/include/config.h` | Pins, periods, limits, and feature settings |

---

## 14. Experiment 9: Trace One Measurement Through The Code

**Goal:** follow one physical measurement from the sensor to the algorithm and back to the converter.

First study the flow in [Appendix B](#appendix-b-code-tour-file-by-file), then fill in the blanks without copying blindly:

```text
main.cpp reads sensors by calling __________________________.
Measurements are first stored in a struct named ___________.
The selected algorithm is called by ________________________.
The student function receives a ____________________________.
Panel power is calculated from _____________________________.
The duty cycle is changed through __________________________.
The hardware PWM value is finally written in ______________.
```

| Stage | File and function | Input | Output | Energy or information? |
| --- | --- | --- | --- | --- |
| Physical sensing | | | | |
| Measurement package | | | | |
| Algorithm decision | | | | |
| Duty command | | | | |
| MOSFET switching | | | | |

### Questions

1. At which point does a physical voltage become a software number?
2. At which point does a software number become a switching action?
3. Which path carries energy, and which carries information?
4. Why is the sensor-settling delay checked before the next measurement?

<details>
<summary><strong>Answer check</strong></summary>

```text
readSensors(sample)
PowerStageMeasurements
runSelectedMpptAlgorithm(...)
SolarPanelMeasurement
panelVoltageVolts × panelCurrentAmps
duty.change(...) or duty.set(...)
pwm_manager.cpp
```

</details>

---

# Appendix A: C++ You Will Meet In This Project

Use this appendix when Experiment 5 introduces unfamiliar syntax.

## A.1 Comments

```cpp
// One-line comment.

/*
 * Longer comment.
 */
```

Good comments explain *why* a decision exists rather than translating every symbol into English.

## A.2 Variables and types

```cpp
float panelVoltageVolts = 0.0f;
```

| Type | Example | Use |
| --- | --- | --- |
| `int` | `int direction = -1;` | Whole numbers |
| `float` | `float powerWatts = 0.6f;` | Decimal numbers |
| `bool` | `bool valid = false;` | True/false state |
| `unsigned long` | `unsigned long now = millis();` | Non-negative timing values |

## A.3 Functions

```cpp
float currentDutyCycle = duty.get();
duty.set(0.50f);
duty.change(-smallDutyCycleStep);
```

Functions give names to jobs and hide hardware detail. Student code can request a change without editing timer registers.

## A.4 Header and source files

| File type | Example | Purpose |
| --- | --- | --- |
| Header | `firmware/include/mppt_alg.h` | Declares types and functions |
| Source | `firmware/src/mppt_alg.cpp` | Contains their implementation |

```cpp
#include "mppt_alg.h"
```

Think of a header as a menu of available names and a source file as the place where their work is carried out.

## A.5 Structs

```cpp
struct SolarPanelMeasurement {
    float panelVoltageVolts;
    float panelCurrentAmps;
    float panelPowerWatts;
    float loadVoltageVolts;
    float loadCurrentAmps;
    float loadPowerWatts;
    bool loadSensorIsAvailable;
    float converterDutyCycle;
};
```

A `struct` keeps related values together. Access one field with a dot: `measurement.panelPowerWatts`.

## A.6 Enums

```cpp
enum Mode : uint8_t {
    MODE_AUTO = 0,
    MODE_MANUAL = 1
};
```

An `enum` gives readable names to a limited set of choices.

## A.7 Static memory

```cpp
static float previousPanelPowerWatts = 0.0f;
```

A file-level `static` variable belongs only to that source file and keeps its value between calls. Tracking needs memory because the rule compares a new measurement with an earlier one.

## A.8 Constants

```cpp
const float smallDutyCycleStep = DUTY_STEP_START;
```

`const` tells readers and the compiler that normal code should not rewrite the value.

## A.9 References

```cpp
bool readSensors(PowerStageMeasurements& measurements)
```

The `&` means the function receives the original struct and can fill it in rather than editing a copy.

---

# Appendix B: Code Tour, File By File

## B.1 How the firmware runs

```cpp
void setup() {
    // Runs once after reset.
}

void loop() {
    // Runs again and again.
}
```

Firmware code flow

`setup()` starts Serial, input, I2C, sensors, display, PWM, the optional WiFi dashboard, and initial duty. `loop()` lets several jobs run on separate schedules instead of stopping the whole program with long delays.

| Job | Timing setting |
| --- | --- |
| MPPT control loop | `MPPT_PERIOD_MS` |
| Display update | `DISPLAY_PERIOD_MS` |
| Wait after PWM change | `INA_SETTLE_MS` |
| Soft-start after boot | `SOFTSTART_MS` |

## B.2 `main.cpp`: traffic controller

```cpp
Mode mode = MODE_AUTO;
Algorithm currentAlgorithm = (Algorithm)DEFAULT_MPPT_ALGORITHM;
```

The default algorithm is Incremental Conductance. The loop handles WiFi, button input, mode changes, soft-start, timed measurements, automatic/manual control, and display updates.

The board has two manual controls — the slider and the web page. Only the one last touched should win, so after a web command the firmware ignores the slider until it moves by more than `POT_TAKEOVER_THRESHOLD`:

```cpp
if (isWebManualDutyActive()) {
    float sliderDuty = 0.0f;

    if (readManualDutyIfPotentiometerMoved(sliderDuty)) {
        clearWebManualDuty();
        setConverterDutyCycle(sliderDuty);
        return;
    }

    setConverterDutyCycle(getWebManualDuty());
}
```

This is **control arbitration**: two inputs command one quantity, so software needs an explicit rule for which wins.

## B.3 `sensor_manager.cpp`: measuring the world

`readSensors(PowerStageMeasurements& measurements)` reads the panel sensor and optional load sensor. It clears values first so unavailable data is predictable. The INA226 performs 16-sample internal averaging; the optional software IIR filter is disabled by default.

## B.4 `pwm_manager.cpp`: changing the converter

The PWM manager clamps duty to its configured range, converts the stored float to an 8-bit value from 0 to 255, writes the hardware output, and records when the change occurred.

## B.5 `input_manager.cpp`: human controls

- Short button press: switch Auto/Manual.
- Long button press of about 2 seconds: switch algorithms.
- Slide potentiometer: set manual duty.

The input manager averages ADC readings, applies smoothing, and debounces the button. Nano ESP32 analog inputs are 3.3 V inputs; power the slider from `3V3` or `IOREF`, not fixed 5 V.

## B.6 `display_manager.cpp`: OLED telemetry

The display shows panel and optional load measurements, duty cycle, mode, and algorithm. ESP32 builds also show the unique WiFi name for 15 seconds after startup.

## B.7 `wifi_manager.cpp` and `sweep_manager.cpp`

The WiFi name starts with `EduGrid_` and appends two hexadecimal characters from the final octet of the factory MAC address, for example `EduGrid_A3`. The dashboard reads live values, changes settings, and starts an I–V sweep. A sweep temporarily takes manual control and returns recorded curve data.

## B.8 `mppt_alg.cpp`: student workspace

The student function receives one `SolarPanelMeasurement` and can change duty through the short API. The distributed student section contains a TODO, not a completed P&O solution. The standard P&O selection runs `firmware/src/mppt_alg_reference.cpp`; use Student / Berry to run a student algorithm on the Nano ESP32.

---

# Appendix C: Build And Upload

This project uses PlatformIO.

| Environment | Board |
| --- | --- |
| `nanoatmega328new` | Classic Arduino Nano |
| `arduino_nano_esp32` | Arduino Nano ESP32 |

From `firmware/`:

```bash
pio run -e nanoatmega328new
```

For a Nano ESP32 dashboard build:

```bash
pio run -e arduino_nano_esp32
pio run -e arduino_nano_esp32 -t uploadfs
```

The filesystem upload is required because the board serves dashboard assets from LittleFS.

---

# Appendix D: Debugging Checklist

## Power and wiring

- Is the panel polarity correct?
- Is a teacher-approved load connected?
- Is USB connected for programming and Serial output?
- Are the INA226 devices connected to I2C?
- Is any component unexpectedly hot?

## Software

- Did the correct PlatformIO environment build and upload?
- Is Serial Monitor set to `115200` baud?
- For an ESP32 student program, did you install it with the dashboard's Student / Berry editor?
- For built-in P&O, is P&O selected on the display or dashboard?

## Measurements

- Below `VIN_VALID_MIN`, firmware holds minimum duty.
- Without the panel INA226, MPPT cannot run.
- Without the load INA226, panel MPPT still runs; load values remain unavailable.
- Default 16-sample sensor averaging does not remove every fluctuation.

## Algorithm

- **Which algorithm does the display show?** The board starts in Incremental Conductance. Long-press the button for about 2 seconds to select P&O and run your student code.
- Is the step size too large or too small for 8-bit duty resolution?
- Did you reverse the duty-direction rule?
- Does the first measurement initialize memory rather than compare with an invalid value?
- Did you keep `rememberMeasurement(measurement);`?
- Is an environmental change being mistaken for a perturbation effect?

---

# Appendix E: Glossary

| Term | Meaning |
| --- | --- |
| ADC | Analog-to-digital converter; turns a measured voltage into a number |
| Algorithm | Repeatable set of steps for solving a problem |
| Buck converter | Switching converter that normally reduces output voltage |
| Duty cycle | Fraction of each PWM period spent ON |
| Firmware | Code running on a microcontroller |
| Function | Named block of code that performs a job |
| I–V curve | Current plotted against voltage for a source |
| I2C | Communication bus used by sensors and display |
| INA226 | Sensor chip measuring bus voltage and shunt current |
| `I_sc` | Short-circuit current, measured at `V = 0` |
| MPP | Operating point with maximum electrical power |
| MPPT | Control process that tracks the MPP |
| P–V curve | Power plotted against voltage |
| PWM | Pulse Width Modulation; rapid switching with controlled duty |
| Struct | C++ type grouping related values |
| `V_oc` | Open-circuit voltage, measured at `I = 0` |

---

# Appendix F: Milestones And PDF Export

## Suggested student milestones

### Beginner

- Build and upload the firmware.
- Explain voltage, current, power, `V_oc`, and `I_sc`.
- Use Manual mode to find a high-power duty setting.
- Recover the maximum after a light change without a full sweep.

### Intermediate

- Write and exchange an unambiguous tracking rule.
- Translate the rule into the student C++ section.
- Compare at least two duty step sizes.
- Explain why the algorithm needs previous measurements.

### Advanced

- Add and justify a noise deadband.
- Design an adaptive step-size rule.
- Compare P&O and Incremental Conductance using repeated trials.
- Explain how shade and changing irradiance can confuse a local tracker.
- Trace energy and information paths through the board.

## Exporting this workbook

GitHub renders this Markdown file directly, including the SVG diagrams.

- In GitHub or a browser, open the rendered file and use **Print → Save as PDF**.
- With Pandoc installed, run from the repository root:

```bash
pandoc docs/STUDENT_WORKBOOK.md -o EduGrid_MPPT_Student_Workbook.pdf
```

Keep `docs/assets/` next to the workbook so relative diagram links resolve. The diagrams use flat colours and remain readable when printed in greyscale.

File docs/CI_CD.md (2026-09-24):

# CI/CD and release builds

GitLab CI is defined in `.gitlab-ci.yml` and has two entry points:

- Every push to the default branch rebuilds and deploys the standalone simulation
  dashboard to GitLab Pages.
- Every tag builds a downloadable firmware package. The packaging job verifies
  that the tagged commit belongs to the default branch and fails otherwise.

## Creating a firmware package

Tag a commit that is already on `main`, then push the tag:

```bash
git switch main
git pull --ff-only
git tag -a v1.0.0 -m "EduGrid MPPT v1.0.0"
git push origin v1.0.0
```

The tag pipeline compiles:

- Classic Arduino Nano firmware as an Intel HEX file.
- Arduino Nano ESP32 application firmware.
- Arduino Nano ESP32 LittleFS dashboard image.
- ESP32 bootloader and partition-table recovery images.
- The self-contained standalone dashboard.

Download `edugrid-mppt-<tag>.zip` from the `package-firmware` job artifacts.
The archive contains `SHA256SUMS` and build metadata. Release artifacts do not
expire automatically.

## GitLab Pages

The `deploy-pages` job publishes the current `main` dashboard as both `index.html`
and `edugrid-mppt.html`. The generated page is a single HTML file with its scripts
and styles embedded, so it has no CDN or runtime internet dependency.

GitLab Pages must be enabled in the GitLab project settings. The deployed URL is
shown under **Deploy > Pages** after the first successful `main` pipeline.

## Reproducibility

- JavaScript packages are installed with `npm ci` from `package-lock.json`.
- PlatformIO Core is pinned in CI.
- The AVR and ESP32 PlatformIO platforms are pinned in `firmware/platformio.ini`.
- CI caches downloads but never uses cached build outputs as release artifacts.

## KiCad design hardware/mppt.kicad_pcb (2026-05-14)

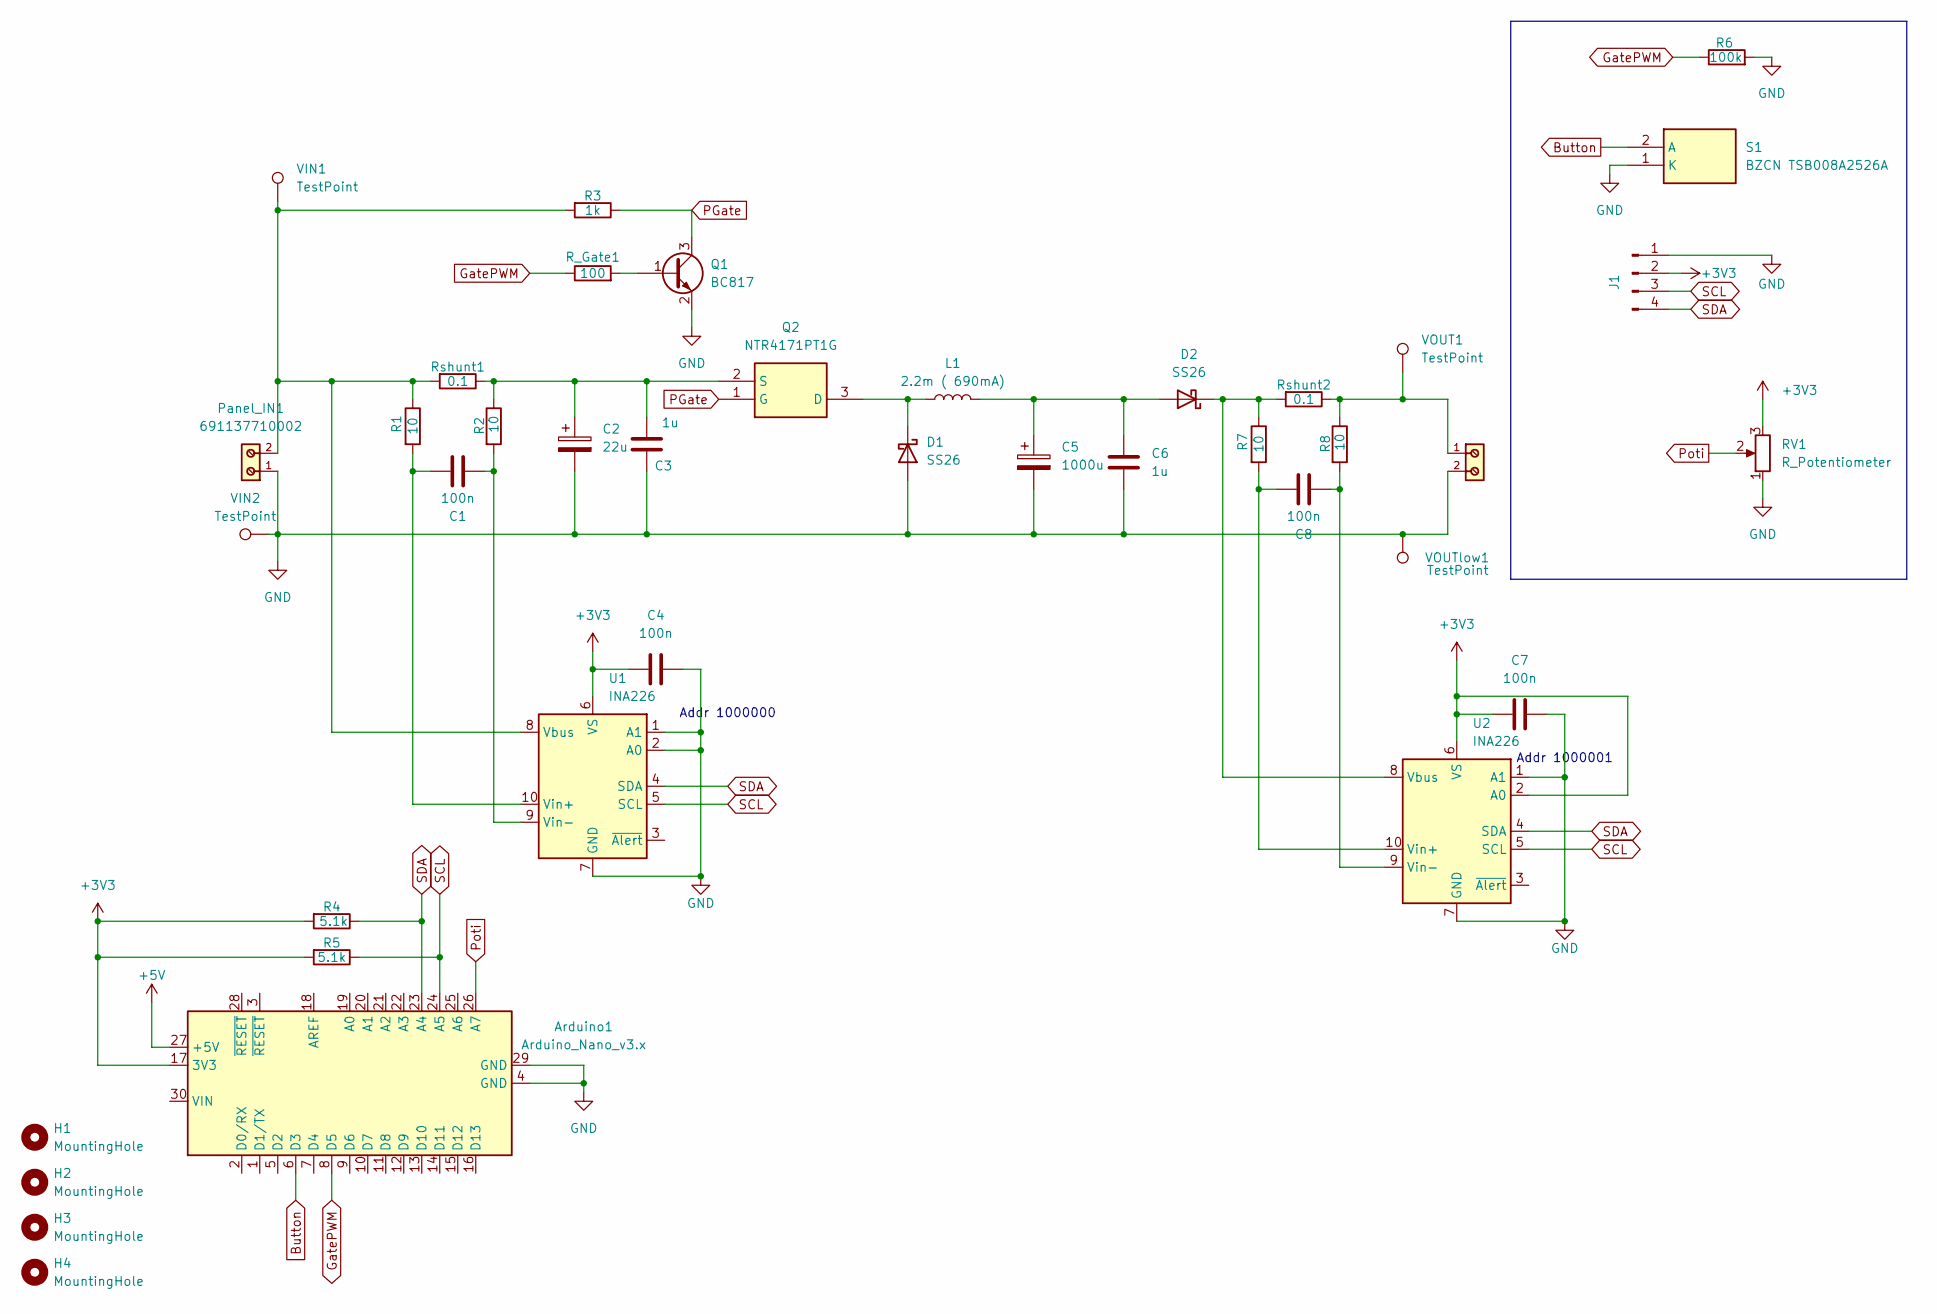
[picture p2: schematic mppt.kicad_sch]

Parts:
Arduino1: Arduino_Nano_v3.x; Arduino_Nano
C1, C4, C7, C8: 100n; C_0805_2012Metric_Pad1.18x1.45mm_HandSolder; LCSC Part # C49678
C2: 22u; CP_Elec_6.3x5.4; LCSC Part # C98744
C3, C6: 1u; C_0805_2012Metric_Pad1.18x1.45mm_HandSolder; LCSC Part # C28323
C5: 1000u; C_Elec_10x10.2; LCSC Part # C401766
D1, D2: SS26; D_SMA; LCSC Part # C47071
H1, H2, H3, H4: MountingHole; MountingHole_3.2mm_M3
J1: Conn_01x04_Pin; PinHeader_1x04_P2.54mm_Vertical
L1: 2.2m ( 690mA); L_Coilcraft_MSS1514V-XXX; LCSC Part # C970554
Panel_IN1: 691137710002
Q1: BC817; SOT-23; LCSC Part # C6807710
Q2: NTR4171PT1G; SOT-23; Manufacturer_Part_Number NTR4171PT1G; Mouser Part Number 863-NTR4171PT1G
R1, R2, R7, R8: 10; R_0805_2012Metric_Pad1.20x1.40mm_HandSolder; LCSC Part # C2907296
R3: 1k; R_0805_2012Metric_Pad1.20x1.40mm_HandSolder; LCSC Part # C17513
R4, R5: 5.1k; R_0805_2012Metric_Pad1.20x1.40mm_HandSolder; LCSC Part # C27834
R6: 100k; LED_0805_2012Metric_Pad1.15x1.40mm_HandSolder
RV1: R_Potentiometer; Potentiometer_Bourns_PTA4543_Single_Slide; JLCPCB Part # C17444183
R_Gate1: 100; R_0805_2012Metric_Pad1.20x1.40mm_HandSolder; LCSC Part # C17408
Rshunt1, Rshunt2: 0.1; R_2512_6332Metric_Pad1.40x3.35mm_HandSolder; LCSC Part # C1021528
S1: BZCN TSB008A2526A; SW_SPST_CK_RS282G05A3; Manufacturer_Part_Number B3U-1000P; Mouser Part Number 653-B3U-1000P
U1, U2: INA226; MSOP-10_3x3mm_P0.5mm; JLCPCB Part # C49851
VIN1, VIN2: TestPoint; TestPoint_Keystone_5005-5009_Compact; LCSC Part # C2906763
VOUT1: TestPoint; TestPoint_Keystone_5005-5009_Compact; LCSC Part # C2906763
VOUT2: 691137710002
VOUTlow1: TestPoint; TestPoint_Keystone_5005-5009_Compact; LCSC Part # C2906763

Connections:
+3V3: Arduino1.17 (3V3), C4.1, C7.1, J1.2, R4.2, R5.2, RV1.3, U1.6 (VS), U2.2 (A0), U2.6 (VS)
+5V: Arduino1.27 (+5V)
Button: Arduino1.6 (D3), S1.2 (A)
GND: Arduino1.4 (GND), Arduino1.29 (GND), C2.2, C3.2, C4.2, C5.2, C6.2, C7.2, D1.2 (A), J1.1, Panel_IN1.1, Q1.2 (E), R6.2, RV1.1, S1.1 (K), U1.1 (A1), U1.2 (A0), U1.7 (GND), U2.1 (A1), U2.7 (GND), VIN2.1, VOUT2.2, VOUTlow1.1
GatePWM: Arduino1.8 (D5), R6.1, R_Gate1.1
unnamed: D1.1 (K), L1.1, Q2.3 (D)
unnamed: C5.1, C6.1, D2.2 (A), L1.2
unnamed: D2.1 (K), R7.1, Rshunt2.2, U2.8 (Vbus)
unnamed: Q1.1 (B), R_Gate1.2
unnamed: C2.1, C3.1, Q2.2 (S), R2.1, Rshunt1.1
unnamed: R8.1, Rshunt2.1, VOUT1.1, VOUT2.1
unnamed: Panel_IN1.2, R1.1, R3.2, Rshunt1.2, U1.8 (Vbus), VIN1.1
unnamed: C1.1, R1.2, U1.10 (Vin+)
unnamed: C1.2, R2.2, U1.9 (Vin-)
unnamed: C8.1, R7.2, U2.10 (Vin+)
unnamed: C8.2, R8.2, U2.9 (Vin-)
PGate: Q1.3 (C), Q2.1 (G), R3.1
Poti: Arduino1.26 (A7), RV1.2
SCL: Arduino1.24 (A5), J1.3, R5.1, U1.5 (SCL), U2.5 (SCL)
SDA: Arduino1.23 (A4), J1.4, R4.1, U1.4 (SDA), U2.4 (SDA)

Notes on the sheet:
Addr 1000000
Addr 1000001

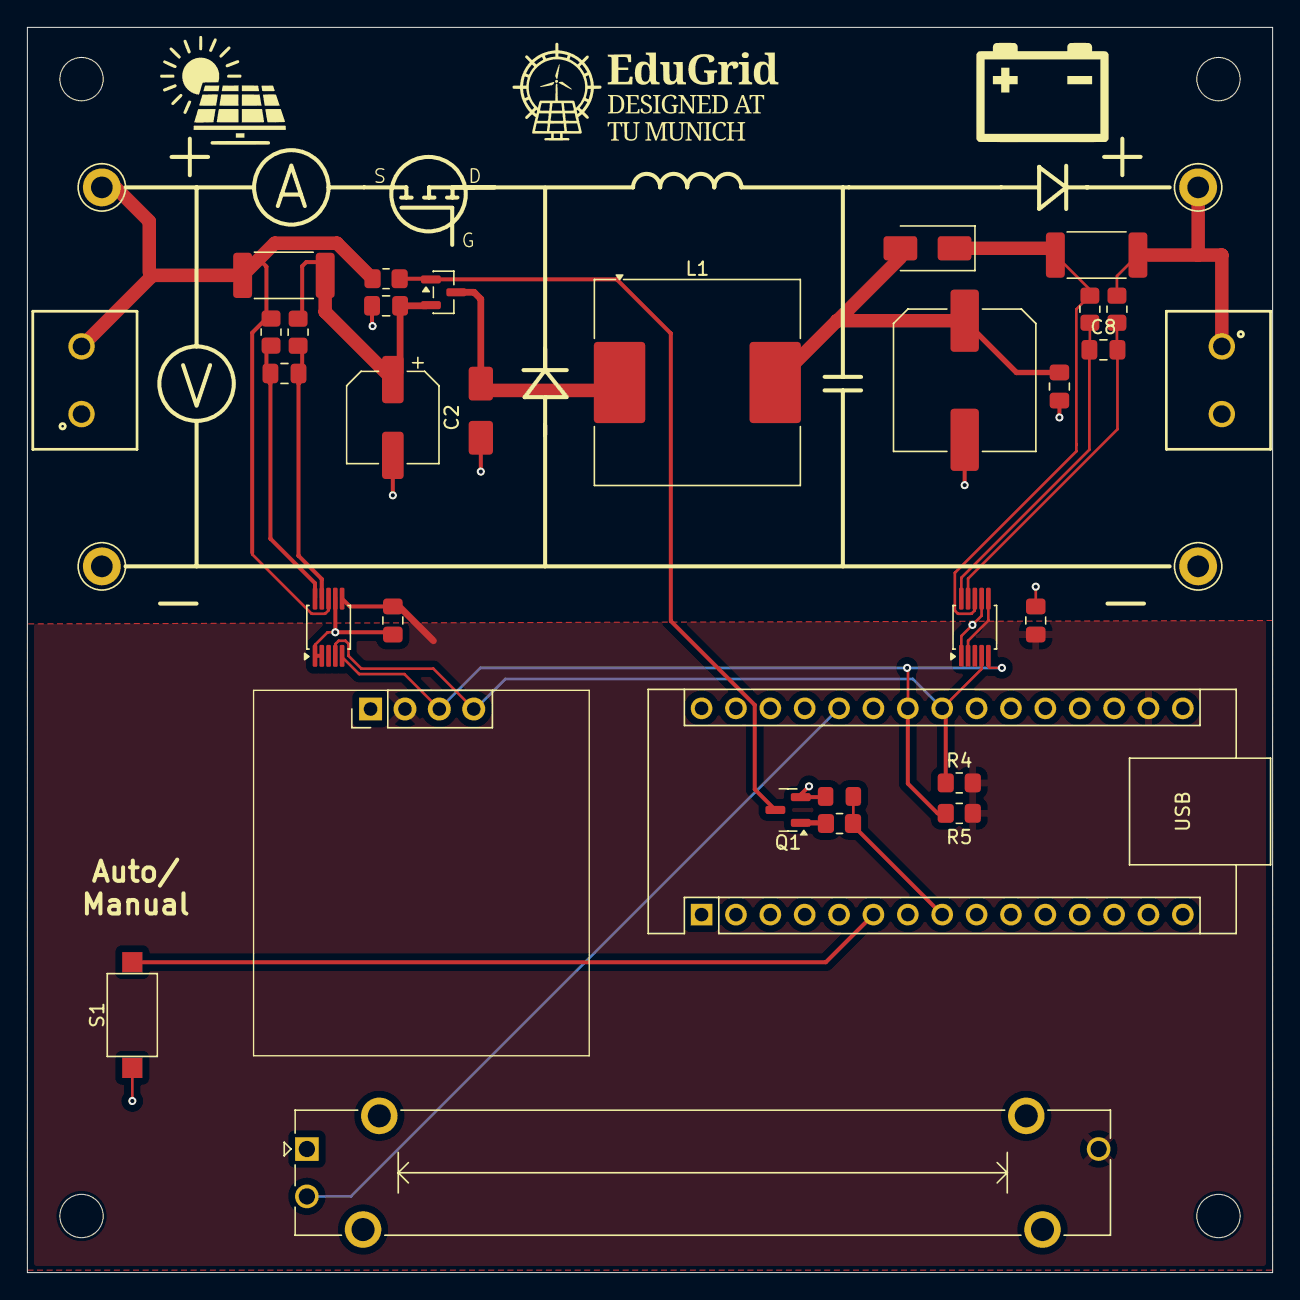
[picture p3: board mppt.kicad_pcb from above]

Board: 2 copper layers, 92.0 x 92.0 mm, 40 parts (0 on the bottom side), 19 nets.

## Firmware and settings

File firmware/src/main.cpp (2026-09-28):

/**
 * @file main.cpp
 * @brief Main firmware loop for the EduGrid MPPT trainer.
 *
 * This file connects the hardware modules together. Students should usually
 * edit mppt_alg.cpp, not this file.
 */

#include <Arduino.h>
#include <Wire.h>
#include "config.h"
#include "pwm_manager.h"
#include "sensor_manager.h"
#include "display_manager.h"
#include "input_manager.h"
#include "mppt_alg.h"
#if defined(ESP32)
#include "berry_manager.h"
#endif

#if defined(ESP32) && ENABLE_WIFI_DASHBOARD
#include "wifi_manager.h"
#include "sweep_manager.h"
#include "ota_manager.h"
#include "log_manager.h"
#endif

// ================= SYSTEM STATE =================
Mode mode = MODE_AUTO;
Mode previousMode = MODE_AUTO;
Algorithm currentAlgorithm = (Algorithm)DEFAULT_MPPT_ALGORITHM;

// ================= MEASUREMENTS =================
float PanelVoltage = 0.0f;
float PanelCurrent = 0.0f;
float PanelPower = 0.0f;
float LoadVoltage = 0.0f;
float LoadCurrent = 0.0f;
float LoadPower = 0.0f;
bool LoadSensorAvailable = false;

// ================= TIMERS =================
unsigned long lastControlLoopMs = 0;
unsigned long startupMs = 0;
unsigned long lastDisplayUpdateMs = 0;

#if defined(ESP32) && ENABLE_WIFI_DASHBOARD
unsigned long wifiSsidDisplayStartMs = 0;
bool wifiSsidDisplayIsActive = false;
#endif

static void printStartupMessage();
static void handleButtonInput(unsigned long now);
static void handleModeChange();
static void runSoftStartIfNeeded(unsigned long now);
static bool readSolarPanelMeasurements();
static void runAutomaticOrManualControl();
static void sendMeasurementsToDashboard();
static bool shouldKeepWiFiSsidOnDisplay(unsigned long now);

void setup() {
    Serial.begin(115200);

    unsigned long serialWaitStart = millis();
    while (!Serial && millis() - serialWaitStart < 1500) {
        delay(10);
    }

    setupInputs();
    printStartupMessage();

    Wire.begin();
    Wire.setClock(400000);

    if (!setupSensor()) {
        Serial.println(F("Panel INA226 sensor init failed"));
    } else {
        Serial.println(F("Panel INA226 sensor init OK"));
    }

    setupDisplay();
    setupPWM();

#if defined(ESP32) && ENABLE_WIFI_DASHBOARD
    setupWiFi();
    setupBerryRuntime();
    displayWiFiAccessPoint(getWiFiSsid());
    wifiSsidDisplayStartMs = millis();
    wifiSsidDisplayIsActive = true;
#endif

    startupMs = millis();
    lastControlLoopMs = startupMs;
    lastDisplayUpdateMs = startupMs;

    setConverterDutyCycle(PWM_MIN_DUTY);
}

void loop() {
    unsigned long now = millis();

#if defined(ESP32) && ENABLE_WIFI_DASHBOARD
    handleWiFi();
    if (isOtaSafetyActive()) {
        setConverterDutyCycle(PWM_MIN_DUTY);
        return;
    }
#endif

    handleButtonInput(now);
    handleModeChange();
    runSoftStartIfNeeded(now);

    bool timeForControlLoop =
        now - lastControlLoopMs >= MPPT_PERIOD_MS;

    if (timeForControlLoop) {
        lastControlLoopMs = now;

        bool sensorSettled =
            now - getLastPwmChange() >= INA_SETTLE_MS;

        if (sensorSettled && readSolarPanelMeasurements()) {
            sendMeasurementsToDashboard();
#if defined(ESP32) && ENABLE_WIFI_DASHBOARD
            recordLogSample(now, PanelVoltage, PanelCurrent, LoadVoltage, LoadCurrent,
                            LoadSensorAvailable, getConverterDutyCycle());
#endif
            runAutomaticOrManualControl();
        }
    }

    bool timeForDisplay =
        now - lastDisplayUpdateMs >= DISPLAY_PERIOD_MS;

    if (timeForDisplay) {
        lastDisplayUpdateMs = now;
        if (shouldKeepWiFiSsidOnDisplay(now)) {
            return;
        }

        displayTelemetry(PanelPower,
                         PanelVoltage,
                         PanelCurrent,
                         LoadPower,
                         LoadVoltage,
                         LoadCurrent,
                         LoadSensorAvailable,
                         getConverterDutyCycle(),
                         mode,
                         currentAlgorithm);
    }
}

static bool shouldKeepWiFiSsidOnDisplay(unsigned long now) {
#if defined(ESP32) && ENABLE_WIFI_DASHBOARD
    if (!wifiSsidDisplayIsActive) {
        return false;
    }

    if (now - wifiSsidDisplayStartMs < WIFI_SSID_DISPLAY_MS) {
        return true;
    }

    wifiSsidDisplayIsActive = false;
#endif

    return false;
}

static void printStartupMessage() {
    Serial.println(F("\nEduGrid MPPT trainer"));
    Serial.println(F("P&O and IncCond built in"));
    Serial.println(F("Gate PWM active; Duty 0-100%"));
    Serial.print(F("INA226 shunt [Ohm]: "));
    Serial.println(SHUNT_OHMS, 6);
}

static void handleButtonInput(unsigned long now) {
    ButtonEvent buttonEvent = checkButtonEvent(now);

    if (buttonEvent == BTN_SHORT_PRESS) {
        mode = (mode == MODE_AUTO) ? MODE_MANUAL : MODE_AUTO;
        Serial.print(F("Mode changed to "));
        Serial.println(mode == MODE_AUTO ? F("AUTO") : F("MANUAL"));
#if defined(ESP32) && ENABLE_WIFI_DASHBOARD
        clearWebManualDuty();
#endif
    } else if (buttonEvent == BTN_LONG_PRESS) {
#if defined(ESP32)
        currentAlgorithm = currentAlgorithm == ALGORITHM_INCCOND
            ? ALGORITHM_PNO
            : currentAlgorithm == ALGORITHM_PNO
                ? ALGORITHM_BERRY
                : ALGORITHM_INCCOND;
#else
        currentAlgorithm = (currentAlgorithm == ALGORITHM_INCCOND) ? ALGORITHM_PNO : ALGORITHM_INCCOND;
#endif

        Serial.print(F("Algorithm changed to "));
        Serial.println(currentAlgorithm == ALGORITHM_INCCOND
            ? F("IncCond")
            : currentAlgorithm == ALGORITHM_BERRY ? F("Berry") : F("P&O"));
        resetMPPT();
#if defined(ESP32)
        if (currentAlgorithm == ALGORITHM_BERRY) resetBerryMppt();
#endif
    }
}

static void handleModeChange() {
    if (mode == previousMode) return;

    if (mode == MODE_AUTO) {
        resetMPPT();
#if defined(ESP32)
        if (currentAlgorithm == ALGORITHM_BERRY) resetBerryMppt();
#endif
    }

    previousMode = mode;
}

static void runSoftStartIfNeeded(unsigned long now) {
    if (now - startupMs >= SOFTSTART_MS) return;

    float startupProgress =
        (now - startupMs) / (float)SOFTSTART_MS;
    float softStartDuty =
        PWM_MIN_DUTY + startupProgress * (0.5f - PWM_MIN_DUTY);

    setConverterDutyCycle(softStartDuty);
}

static bool readSolarPanelMeasurements() {
    PowerStageMeasurements sample;

    if (!readSensors(sample)) {
        setConverterDutyCycle(PWM_MIN_DUTY);
        delay(1);
        return false;
    }

    LoadSensorAvailable = sample.loadSensorIsReady;

    PanelVoltage = sample.panelVoltageVolts;
    PanelCurrent = sample.panelCurrentAmps;
    PanelPower = sample.panelPowerWatts;
    LoadVoltage = sample.loadVoltageVolts;
    LoadCurrent = sample.loadCurrentAmps;
    LoadPower = sample.loadPowerWatts;

    return true;
}

static void sendMeasurementsToDashboard() {
#if defined(ESP32) && ENABLE_WIFI_DASHBOARD
    if (isSweeping()) {
        if (updateSweep()) {
            broadcastSweepDone();
        }
    } else {
        broadcastMpptData(PanelVoltage,
                          PanelCurrent,
                          PanelPower);
    }
#endif
}

static void runAutomaticOrManualControl() {
#if defined(ESP32) && ENABLE_WIFI_DASHBOARD
    if (isSweeping()) return;
#endif

    if (mode == MODE_AUTO) {
        if (PanelVoltage < VIN_VALID_MIN) {
            setConverterDutyCycle(PWM_MIN_DUTY);
            Serial.println(F("Panel voltage too low; holding minimum duty"));
            return;
        }

        runSelectedMpptAlgorithm(PanelVoltage,
                                 PanelCurrent,
                                 LoadVoltage,
                                 LoadCurrent,
                                 LoadSensorAvailable,
                                 currentAlgorithm);
        return;
    }

#if defined(ESP32) && ENABLE_WIFI_DASHBOARD
    if (isWebManualDutyActive()) {
        float sliderDuty = 0.0f;

        if (readManualDutyIfPotentiometerMoved(sliderDuty)) {
            clearWebManualDuty();
            setConverterDutyCycle(sliderDuty);
            return;
        }

        setConverterDutyCycle(getWebManualDuty());
        return;
    }
#endif

    float sliderDuty = readManualDuty();
    setConverterDutyCycle(sliderDuty);
}

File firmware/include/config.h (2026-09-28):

/**
 * @file config.h
 * @brief Configuration constants and settings for the MPPT Buck Converter.
 *
 * This file contains all the user-configurable settings, pin definitions,
 * and system constants. It also defines the operating modes and algorithm selection.
 */

#pragma once

#include <stdint.h>
#include <Arduino.h>

// ================= HARDWARE SETTINGS =================
#define PANEL_INA_ADDR  0x40  /** @brief I2C address of the panel/input-side INA226 sensor. */
#define LOAD_INA_ADDR   0x41  /** @brief I2C address of the load/output-side INA226 sensor. */
#define INA_ADDR        PANEL_INA_ADDR /** @brief Backward-compatible name for the panel INA226 address. */
#define SHUNT_OHMS      0.1f  /** @brief Value of each current shunt resistor in Ohms. */
#define INA_MAX_CURRENT 0.2f  /** @brief Maximum expected current in Amps (used for INA226 calibration). */
#define INA_AVERAGE_MODE 2    /** @brief INA226 averaging: 0=1, 1=4, 2=16, 3=64, ... 7=1024 samples. */
#define INA_CONVERSION_TIME_MODE 4 /** @brief INA226 conversion time: 4=1100us for bus and shunt. */

#if defined(ARDUINO_NANO_ESP32) || defined(ARDUINO_ARDUINO_NANO_ESP32)
    // Arduino Nano ESP32 (S3) - Drop-in replacement for Nano
    // Uses the Arduino Pin Definitions to map to the correct physical location
    #define GATE_PIN        D5  /** Nano ESP32 D5 maps to ESP32-S3 GPIO8. */
    #define BTN_PIN         D3  /** Nano ESP32 D3 maps to ESP32-S3 GPIO6. */
    #define POT_PIN         A7 /** Nano ESP32 A7 maps to ESP32-S3 GPIO14. */
    #define ENABLE_WIFI_DASHBOARD 1
    
    // WiFi Settings
    #define WIFI_SSID_PREFIX "EduGrid_"
    #define WEB_PORT         80
    #define CAPTIVE_DNS_PORT 53

#else
    #define GATE_PIN        9 /** @brief Pin number for the Buck converter MOSFET gate (OC1A on Uno/Nano). */
    #define BTN_PIN         3  /** @brief Pin number for the mode toggle button (connected to GND). */
    #define POT_PIN         A7 /** @brief Pin number for the potentiometer (manual duty control). */

#endif

#ifndef ENABLE_WIFI_DASHBOARD
#define ENABLE_WIFI_DASHBOARD 0
#endif

#ifndef WIFI_SSID_PREFIX
#define WIFI_SSID_PREFIX "EduGrid_"
#endif

#ifndef CAPTIVE_DNS_PORT
#define CAPTIVE_DNS_PORT 53
#endif

// ================= PWM SETTINGS =================
#define PWM_MIN_DUTY    0.0f    /** @brief Minimum allowed PWM duty cycle (0.0 to 1.0). */
#define PWM_MAX_DUTY    1.0f   /** @brief Maximum allowed PWM duty cycle (0.0 to 1.0). */

// ================= MPPT ALGORITHM SETTINGS =================
#define ALGO_INCCOND    0 /** @brief Identifier for the Incremental Conductance algorithm. */
#define ALGO_PNO        1 /** @brief Identifier for the Perturb & Observe algorithm. */
#define DEFAULT_MPPT_ALGORITHM  ALGO_INCCOND /** @brief Default MPPT Algorithm. */

#define MPPT_PERIOD_MS  100      /** @brief Time interval between MPPT updates in milliseconds. */ // 10 Hz MPPT loop
#define DUTY_STEP_MIN   0.002f   /** @brief Minimum step size for duty cycle adjustment. */
#define DUTY_STEP_MAX   0.02f    /** @brief Maximum step size for duty cycle adjustment. */
#define DUTY_STEP_START 0.01f    /** @brief Default step size for duty cycle adjustment. */
#define SOFTSTART_MS    1000     /** @brief Duration of the soft-start phase in milliseconds. */
#define SENSOR_IIR_ALPHA 0.2f    /** @brief Low-pass filter coefficient (0.0 to 1.0). Higher = less smoothing. */
/** @brief Enable the optional software IIR filter on sensor readings (1=on, 0=off). */
#define ENABLE_SENSOR_IIR_FILTER 0
#define COMPARE_MEASUREMENT_FILTERS 1 /** @brief Print raw-vs-filtered sensor data over Serial when enabled. */
#define FILTER_COMPARE_PERIOD_MS 1000 /** @brief Interval for raw-vs-filtered Serial comparison. */
#define VIN_VALID_MIN   0.5f     /** @brief Minimum valid input voltage to start MPPT. */
#define IIN_VALID_MIN   0.0f     /** @brief Minimum valid input current. */
#define INA_SETTLE_MS   5        /** @brief Wait time after PWM change before measuring (INA conversion time). */
#define FIRST_KICK_STEP 0.05f    /** @brief Initial duty cycle disturbance when entering Auto mode. */

// ================= ESP32 BERRY STUDENT RUNTIME =================
#define BERRY_SOURCE_MAX_BYTES       4096U  /** @brief Maximum uploaded Berry source size. */
#define BERRY_COMPILE_TIMEOUT_MS      250U  /** @brief Maximum compile/top-level execution time. */
#define BERRY_STEP_TIMEOUT_MS          20U  /** @brief Maximum time for one mppt() call. */
#define BERRY_MAX_DUTY_CHANGE        0.05f  /** @brief Maximum absolute duty change per MPPT call. */
#define BERRY_MIN_FREE_HEAP_BYTES   32768U  /** @brief Reject activation if ESP32 heap is below this. */

/** @brief Debounce time for the button in milliseconds. */
#define BTN_DEBOUNCE_MS 30

/** @brief Update interval for the OLED display in milliseconds. */
#define DISPLAY_PERIOD_MS 50

/** @brief Time to show the WiFi SSID on the OLED after boot. */
#define WIFI_SSID_DISPLAY_MS 15000UL
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

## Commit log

2025-12-21 Initial commit - EduGrid MPPT with ESP32 support
2025-12-21 added arduino mppt board picture
2025-12-24 added KiCad files
    [mppt.kicad_pcb, mppt.kicad_sch]
2025-12-24 restructured directories
    [mppt.kicad_pcb, mppt.kicad_sch]
2026-02-18 updated version
    [mppt.kicad_pcb, mppt.kicad_sch]
2026-02-18 include temporary kicad outputs
2026-02-21 added KiCad output files
2026-02-27 added measurment to output
    [bom.csv, designators.csv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]
2026-03-08 added output measurements and adjusted components
    [mppt.kicad_pcb, mppt.kicad_sch]
2026-03-08 Remove production files from tracking and respect .gitignore
    [bom.csv, designators.csv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]
2026-05-14 Complete rework of functions and frontend
    [config.h, display_manager.cpp, input_manager.cpp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]
2026-05-14 Connected 3.3V instead of 5V to slider poti. This makes the full range available for esp32 and avoids damage to the board
    [mppt.kicad_pcb, mppt.kicad_sch]
2026-06-15 added esp32c3 super mini as replacement for esp32 nano
    [config.h]
2026-06-15 Change the WiFi SSID to include the chipID for identification when there's multiple devices. SSID is hown for 15 seconds on startup of the esp
2026-06-15 changed the power graph axis dynamically, add more precision to the measurments display
2026-06-15 changes in the frontend and added the esp32c3mini library to the kicad project
2026-09-20 Fix optional sensor filter configuration
    [config.h]
2026-09-20 Correct duty range and slider terminology
    [config.h, main.cpp]
2026-09-20 T-1.2 Irradiance and temperature scaling
2026-09-20 T-2.1 Buck converter with a real load
2026-09-20 fix: include panel power in operating points
2026-09-20 docs: record remaining MS2 dependency chain
2026-09-20 T-1.6 Add deterministic sensor noise
2026-09-20 T-2.3 Wire panel presets into dashboard
2026-09-20 T-3.3 Add rolling power chart
2026-09-22 Run restricted Berry algorithms on ESP32
2026-09-22 Add browser OTA recovery for ESP32
2026-09-24 Clarify and tighten Berry benchmark layout
2026-09-25 Make Berry benchmark track changing MPP
2026-09-26 Add ESP32 experiment logging and passwordless dashboard access
2026-09-27 Keep dashboard power axes readable above 2 W
2026-09-30 Tighten I-V chart scale and simulation voltage range
